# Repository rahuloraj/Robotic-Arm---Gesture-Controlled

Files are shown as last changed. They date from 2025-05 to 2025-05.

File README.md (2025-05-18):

<h1 align="center">Gesture Controlled Robotic Arm</h1>

<p align="center">
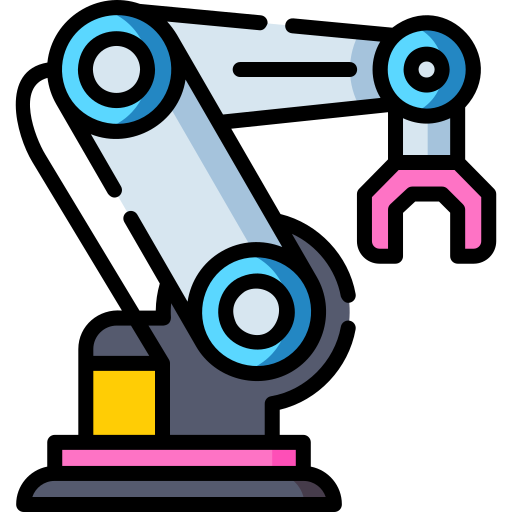
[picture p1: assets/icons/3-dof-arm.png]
3-DOF Arm
  
</p>

<details>
  <summary><h2>📚 Table of Contents (Click to Expand)</h2></summary>

- [📖 Project Description](#-project-description)
- [✨ Features](#-features)
- [⚙️ Installation Instructions](#️-installation-instructions)
- [🦾 Project Showcase](#-project-showcase)
- [🔧 Use Cases](#-use-cases)
- [🛣️ Future Plans](#️-future-plans)
- [🤝 Contributing](#-contributing)
- [📜 License](#-license)
- [🙏 Acknowledgments](#-acknowledgments)
  - [🤖 Meet the Team! 🤝](#-meet-the-team-)
- [📧 Contact Information](#-contact-information)
- [📝 Attribution](#-attribution)
</details>

---

## 📖 Project Description  

The **Gesture-Controlled Robotic Arm** is designed to automate repetitive tasks using hand gestures. The robotic arm consists of **four links**: a **base, two links, and an end effector**, enabling **pick-and-place functionality**.  

Control is achieved via a **glove-based gesture system**, equipped with **flex sensors and an accelerometer**, translating hand movements into precise robotic commands.

---

## ✨ Features  

🤖 4-Link Robotic Arm Structure
    ➤ Enables precise and flexible movement

🖐️ Gesture-Based Control
    ➤ Uses flex sensors and an accelerometer for intuitive interaction

📦 Pick-and-Place Functionality
    ➤ Automates repetitive tasks with ease

🧭 Intuitive User Interface
    ➤ Offers seamless and user-friendly control 

> **Note:**  
> The integration of a 4th link between the end effector and the robotic arm is part of our planned system expansion.  
> In the current release, the design has been optimized for stability, ease of control, and project timelines.  
> Full 4-link integration, offering enhanced dexterity and extended functionality, is scheduled for future updates.  
> Further design considerations and future rollout details are outlined in the [DESIGN.MD](./designs/DESIGN.MD) file.
---

## ⚙️ Installation Instructions  

- 🛠️ For installation instructions and to download the Arduino IDE, visit the [Arduino IDE Download Page](https://www.arduino.cc/en/software).
- Add the ESP32 Library to the ide [Instructions](https://docs.espressif.com/projects/arduino-esp32/en/latest/installing.html)
- To set up the project, follow these steps: 
- Clone the repository:
- ```bash
  git clone https://github.com/Robo-Linkers/Gesture-controlled-robotic-arm.git 
  ```
- Install any necessary dependencies [REQUIREMENTS](requirements.txt)
- Navigate to the project directory:
- ```cd Gesture-controlled-robotic-arm```
- In the `src` folder, you will find two Arduino code files: `Glove.ino` and `Power_Drive.ino`.
  - Upload `Glove.ino` to the ESP32 board that handles gesture recognition.
  - Upload `Power_Drive.ino` to the ESP32 board that controls the robotic arm's movements.
- Before uploading the codes to the boards, make sure to:
  - Edit the relevant fields in both files:
    - Set your WiFi SSID and Password in the code.  
    - Adjust any other parameters as necessary for your setup (e.g., GPIO pins, motor controls).

Once you've uploaded both codes to the respective boards, your setup should be ready for further testing.
- For building the hardware and assembling the robotic arm, refer to the detailed setup and wiring instructions in the [DESIGN.MD](./designs/DESIGN.MD) file. This includes schematics, PCB & hardware designs, and wiring connections necessary to physically construct the system.
-  All Markdown files are available as HTML in the [docs/](./docs) section — check it out for easy browsing and reference.
-  [README.HTML](https://html-preview.github.io/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), [DESIGN.HTML](https://html-preview.github.io/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), [TESTS.HTML](https://html-preview.github.io/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), [BOM.HTML](https://html-preview.github.io/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)
---

## 🚀 Usage Instructions  
- After setting up the hardware and software, wear the glove equipped with sensors, power on the robotic arm, and start performing gestures to control its movements.
  ### Components
  - Robotic Arm: 4-link structure with servos.
  - Glove Interface: Equipped with flex sensors and an accelerometer
  - Microcontroller: ESP32 or compatible board for processing input signals
  - Power Supply: AC power source for operation.
  ### Designs
  - For detailed information on the setup, schematics, and design documents related to the glove and robotic arm, refer to the Design Folder. It includes all the necessary diagrams and documentation to help you build the physical system and understand the circuitry.
  ### Testing
  - The tests folder contains Arduino sketches for testing individual components, including:
    - Flex sensors
    - Dual MPU6050
    - Power electronics (motors, servos)
  - If you encounter any errors, test each component individually to identify the source of the issue. 
  > It is **highly recommended** to test each component individually before full assembly to ensure everything is working correctly and to avoid complications during the final integration.

---

## 📂 Folder Structure  
```bash
Gesture-controlled-robotic-arm/
│   .gitignore
│   CONTRIBUTING.md
│   LICENSE
│   README.md
│   requirements.txt
│   TODO.MD
│   
├───assets
│   ├───icons
│   │       3-dof-arm.png
│   │       bill.png
│   │       binary-code.png
│   │       docs.png
│   │       pcb-board.png
│   │       schematic.png
│   │       testing.png
│   │
│   └───images
│           feature-excluded.png
│           mechanical-assembly-ss-front.png
│           mechanical-assembly-ss.png
│           Screenshot 2025-02-11 091135.png
│           Screenshot 2025-02-11 091319.png
│
├───designs
│   │   BASE v14.step
│   │   Bill_of_Materials_Electrical.pdf
│   │   BOM.MD
│   │   DESIGN.MD
│   │   Schematic_Glove-Gesture-Controlled-Robotic-Arm_2025-04-26.pdf
│   │   Schematic_Power-Drive-Gesture-Controlled-Robotic-Arm_2025-04-26.pdf
│   │
│   └───Solid-edge
│           BASE-v14-solid-edge.asm
│           BASE-v14-solid-edge.cfg
│
├───docs
├───logs
│       glove_control.log
│       power_drive.log
│
├───src
│       Glove.ino
│       Power_Drive.ino
│
├───tests
│   │   TESTS.MD
│   │
│   ├───Embedded Systems
│   │   ├───COMPLETE
│   │   │       COMPLETE.ino
│   │   │
│   │   ├───DUAL-MPU6050
│   │   │       DUAL-MPU6050.ino
│   │   │
│   │   └───FLEX-SENSORS
│   │           FLEX-SENSORS.ino
│   │
│   └───Power Electronics
│       ├───complete
│       │       complete.ino
│       │
│       ├───complete-dynamic
│       │       complete-dynamic.ino
│       │
│       ├───nema_17_test
│       │       nema_17_test.ino
│       │
│       └───servo_test
│               servo_test.ino
.
```
---

## 🦾 Project Showcase
<!-- Add vids, images etc -->

---

## 🔧 Use Cases  

💡 **Manufacturing** → Automating repetitive tasks like assembly & packaging  
🔧 **Remote Operation in Hazardous Environments** → Safely handling objects in high-risk areas such as labs or hot zones using remote gesture control
🎓 **Education** → Demonstrating robotics concepts in academic settings  
🧪 **Research** → Exploring human-robot interaction and automation  

---

## 🛣️ Future Plans
- 🚀 **Integrate the 4th Link**
  - Expand the robotic arm with a fourth link between the end effector and arm base to improve dexterity and range of motion.

- 🚀 **Enhance Gesture Recognition**
  - Implement advanced gesture processing algorithms for more fluid and natural control.

- 🚀 **Wireless Communication Optimization**
  - Improve reliability and response time of the ESP32-based communication system.

- 🚀 **Battery Power Support**
  - Add portable power options to make the system independent of a fixed AC supply and make a rechargeable solution for glove.

- 🚀 **Vision-Based Object Tracking**
  - Future iterations may incorporate a lightweight camera module for autonomous object detection and tracking.

- 🚀 **Mechanical Redesign**
  - Refine the mechanical structure for lighter weight and increased durability, including 3D printed or CNC-milled parts.

---

## 🤝 Contributing  
- Contributions are welcome! Please feel free to submit a pull request or open an issue if you have suggestions or improvements, for more details refer [CONTRIBUTING](CONTRIBUTING.md).

---

## 📜 License  

This project is licensed under the **MIT License**. Refer to the [LICENSE](LICENSE) file for more details.  

---

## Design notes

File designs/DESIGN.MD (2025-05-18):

<h1 align="center">Design Folder</h1>

<p align="center">
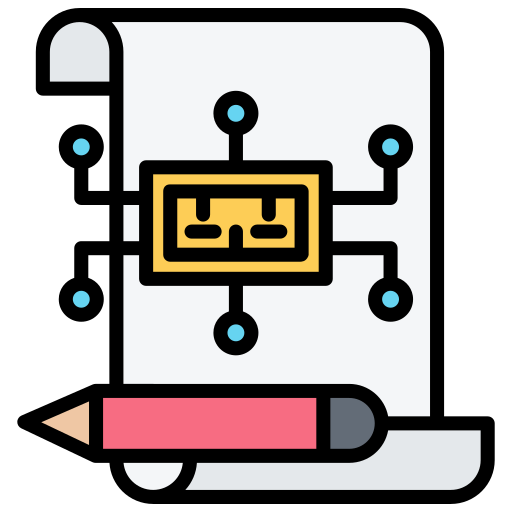
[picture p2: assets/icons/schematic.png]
Design
  
</p>

## Table of Contents
- [Table of Contents](#table-of-contents)
- [📖 Overview](#-overview)
- [🛠️ Implementation Note](#️-implementation-note)
- [📂 Schematic Files](#-schematic-files)
  - [🔌 1. Power Electronics Schematic](#-1-power-electronics-schematic)
  - [Final PCB for Power Drive](#final-pcb-for-power-drive)
  - [🖐️ 2. Embedded System Schematic](#️-2-embedded-system-schematic)
  - [Final PCB for Glove Control](#final-pcb-for-glove-control)
- [🛠️ Wiring Instructions](#️-wiring-instructions)
- [🦿 Mechanical Design Overview](#-mechanical-design-overview)
  - [📂 Mechanical Design Files](#-mechanical-design-files)
  - [🖼️ Final Mechanical Build](#️-final-mechanical-build)
  - [🛠️ Assembly Instructions](#️-assembly-instructions)
  - [⚠️ Mechanical Handling Notes](#️-mechanical-handling-notes)
    - [Image of the Feature Excluded:](#image-of-the-feature-excluded)
- [🔗 Useful Links](#-useful-links)

## 📖 Overview  

This folder contains three important schematic files related to the design of the Robotic Arm project. Each schematic serves a specific purpose and is crucial for the development and integration of the power electronics and embedded systems.
> 📄 All schematics are provided in PDF format for easy viewing and printing.
> All the voltages mentioned are in DC unless specified.
> Designed and documented by **IoRT Club** - Embedded & Power Crew.

---

## 🛠️ Implementation Note

You can implement the electronics in two ways:

- **Custom PCB**:  
  Build a dedicated PCB by referring to the provided schematics for a more compact and reliable design.

  You can design the PCB using free tools such as:
  - [KiCad](https://www.kicad.org/) — Open-source, highly customizable PCB design software.
  - [EasyEDA](https://easyeda.com/) — Browser-based and beginner-friendly PCB design platform.

  > **Note**: Both tools are free to use (with some limitations).    
  After completing your design, export the files in **Gerber format** and submit them to a PCB fabrication vendor for manufacturing.

- **Perfboard / Breadboard**:  
  Alternatively, for prototyping or quick builds, you can assemble the circuits manually on a perfboard by carefully following the schematic connections. 
  Using a perfboard is recommended if manufacturing a custom PCB is not feasible or practical.

> **Note**: Ensure proper wire management and soldering practices if you choose the perfboard method to maintain signal integrity and minimize errors.

---

## 📂 Schematic Files

### 🔌 1. Power Electronics Schematic 

- **File Name**: [Schematic_Power-Drive-Gesture-Controlled-Robotic-Arm_2025-04-26](Schematic_Power-Drive-Gesture-Controlled-Robotic-Arm_2025-04-26.pdf)
- **Description**: This schematic implements the power drive for the robotic arm, including the configuration for servos and motors. It outlines how power is managed and distributed to ensure optimal performance of the robotic arm's movements.
  - Handles the actuation part of the robotic arm including control for servos and a NEMA17 stepper motor.
  - Features motor driving using DRV8825 for stepper control and PCA9685 for multi-servo PWM output.
  - Power management done using LM2596 buck converter and dual LM7805 regulators.
- **Key ICs**:
  - ESP32-WROOM32
  - DRV8825 Stepper Motor Driver
  - PCA9685 16-Channel PWM Driver
  - LM2596 Adjustable Buck Converter
  - LM7805 Voltage Regulators
- **Notes**:
  - Main voltage input via XT60 connector (e.g., 12V supply).
  - Separate regulation for logic and motor sections to avoid noise.

> ⚠️ **Power Safety Warning**  
> 
> The Power Drive system is designed to operate using a **12V DC SMPS (Switched-Mode Power Supply)** rated at a minimum of **2.5A**.  
> 
> Please exercise extreme caution while handling the power system:
> - Ensure the SMPS is properly rated and from a reputable manufacturer.
> - Always verify polarity before connecting the supply to the circuit.
> - Never work on the circuit while the SMPS is powered ON.
> - Use appropriate fuses or protection circuits if possible.
> 
> 🔥 Mishandling the power supply can cause **serious damage to components** or **pose a fire hazard**.  
> Double-check all connections before powering the system.

### Final PCB for Power Drive
<div align="center">
<!-- PCB for Power Drive -->
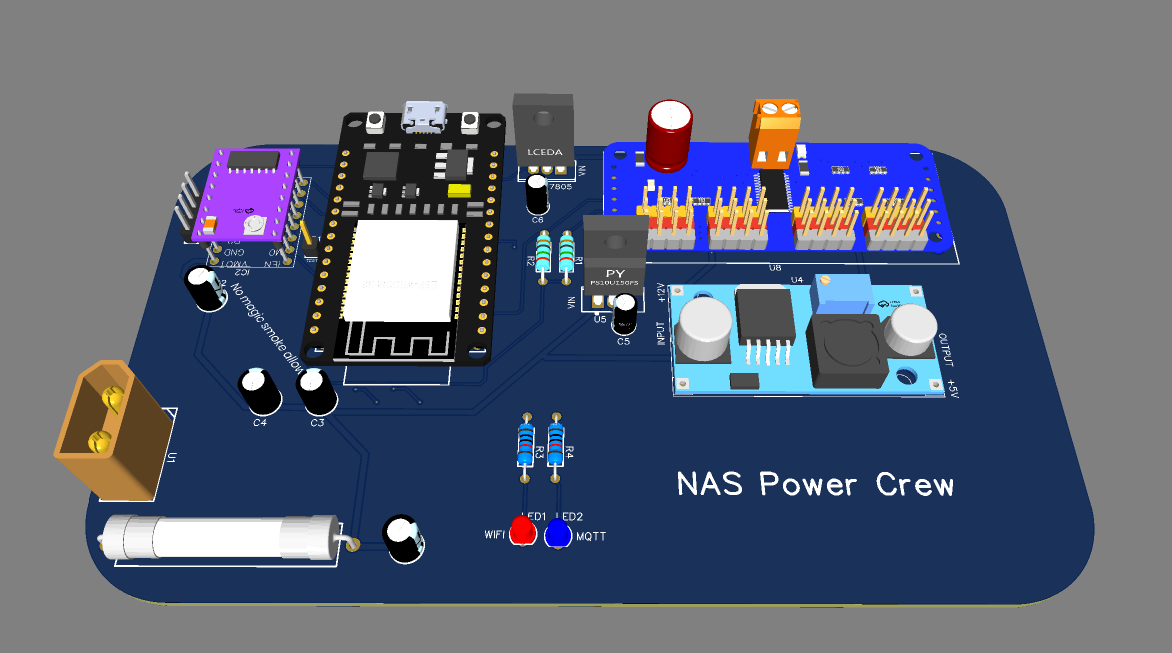
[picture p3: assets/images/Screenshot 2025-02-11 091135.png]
Final PCB for Power Drive

</div>

### 🖐️ 2. Embedded System Schematic 

- **File Name**: [Schematic_Glove-Gesture-Controlled-Robotic-Arm_2025-04-26](Schematic_Glove-Gesture-Controlled-Robotic-Arm_2025-04-26.pdf)
- **Description**: This schematic details the data acquisition part of the robotic arm, which captures user gestures through a glove interface. It is designed to facilitate communication between the user's gestures and the robotic arm's movements.
  - Captures the user gestures via an ESP32-WROOM32 module, two MPU6050 IMUs, and flex sensors.
  - Features voltage regulation using AMS1117 (3.3V) and LM7805 (5V) to power sensors reliably.
  - Includes TTP223 touch sensors for auxiliary control inputs.
- **Key ICs**:
  - ESP32-WROOM32
  - AMS1117-3.3 Voltage Regulator
  - LM7805 Voltage Regulator
  - Two MPU6050 Modules
  - Flex Sensors
- **Notes**:
  - Operates at 3.3V logic levels.
  - Input supply is 9V regulated down. Ensure the input provided is between 6V to 12V
  - >⚠️ **Note**: The touch sensor feature has been omitted from the current version and is planned for a future release

### Final PCB for Glove Control
<div align ="center">
<!-- Final GLove Control PCB -->
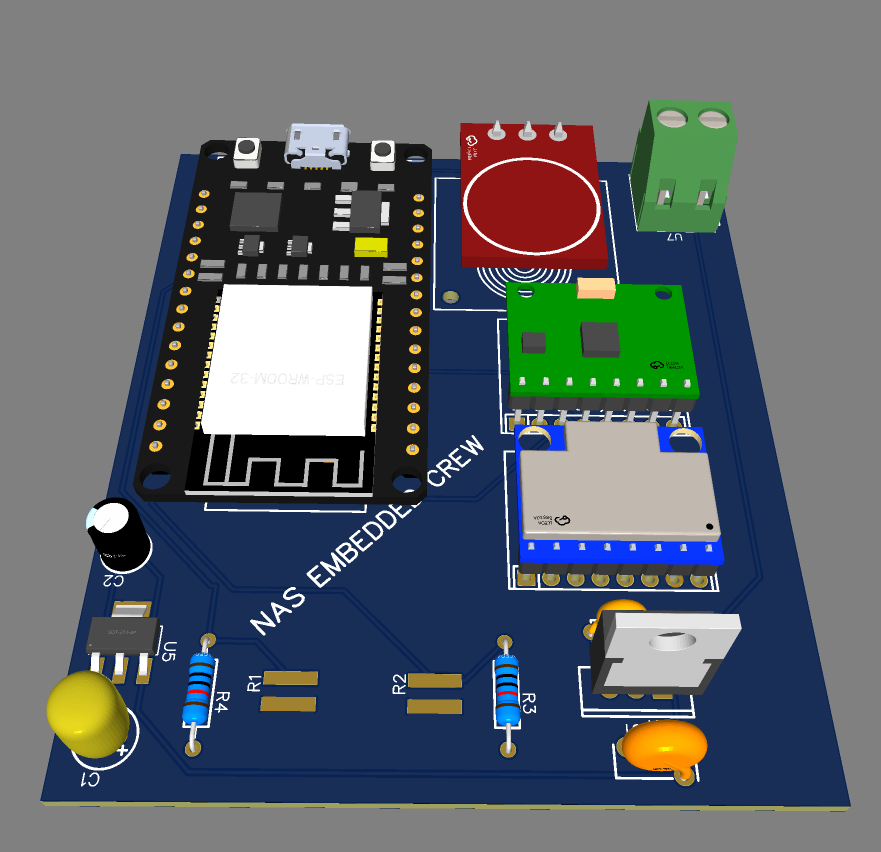
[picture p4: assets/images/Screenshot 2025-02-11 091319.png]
Final Glove Control PCB

</div>

---

## 🛠️ Wiring Instructions
- Ensure the all components are upto the rating as mentioned in the [BOM](Bill_of_Materials_Electrical.pdf)
- Make sure the pinout of your component matches the one provided in the schematic
- If a perfboard based design if being followed ensure that each voltage levels have different rails (think of it as a path for the current), the ground can occupy a single common rail.
-  [🔌 1. Power Electronics Schematic ](#-1-power-electronics-schematic) — 
   -  ESP32-WROOM32:
         - GPIO Pins to control servos via PCA9685.
         - SDA (GPIO21) → SDA of PCA9685
         - SCL (GPIO22) → SCL of PCA9685 

   - PCA 9685
      - Set the buck converter(LM2596) to output a steady voltage of 5.5V
      - The servos are connected to channel 0,1 and 2

   - DRV8825 (Stepper Motor Driver):  
       - DIR (Direction) and STEP pins connected to GPIOs of ESP32 for motor control.
       - Enable pin if required can be connected to a GPIO pin

- [🖐️ 2. Embedded System Schematic ](#️-2-embedded-system-schematic) —
  - MPU6050 IMUs:
    - SDA (GPIO21) and SCL (GPIO22) for I2C communication.
    - One of the MPU6050 IMU has its ADD pin (pin no 7) pulled high to _+3.3V_ this so that both the MPU sensors have unique I2C addresses.

  - Flex Sensors and TTP223 Touch Sensors:
    - Flex sensors and touch sensors connected to the ESP32 analog or digital inputs based on your design.

--- 

## 🦿 Mechanical Design Overview

This section covers the mechanical design aspects of the **Gesture-Controlled Robotic Arm**.  
The structure is designed to be lightweight, modular, and easily reproducible using commonly available materials.

---

### 📂 Mechanical Design Files

- **Formats**: `.step`, `.asm`

---

### 🖼️ Final Mechanical Build

<div align="center">
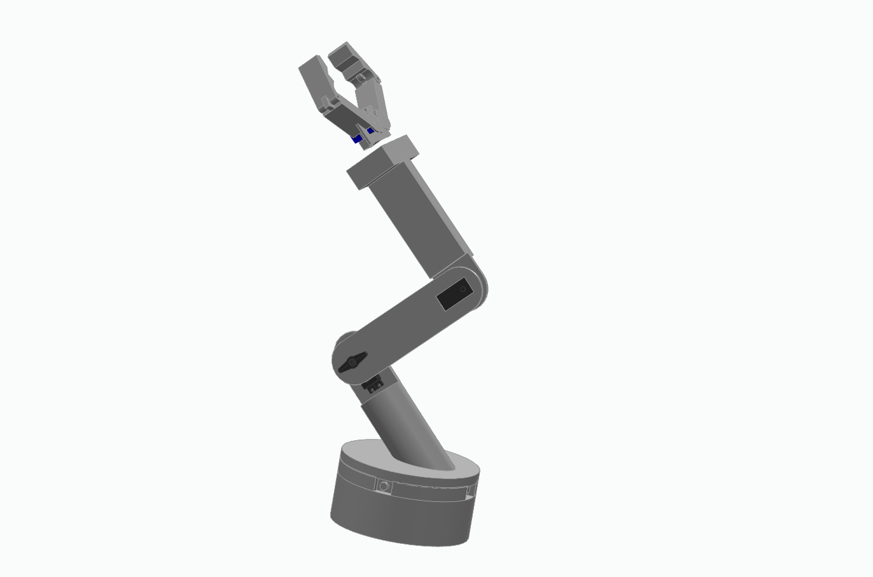
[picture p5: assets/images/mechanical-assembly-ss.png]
Robotic Arm Assembly Side View

</div>

<div align="center">
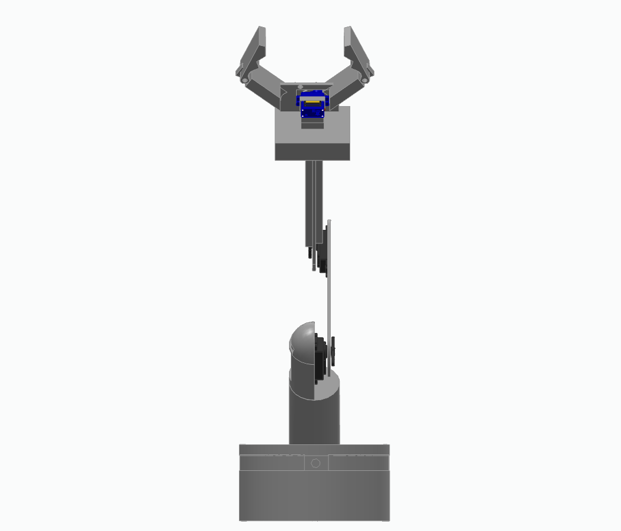
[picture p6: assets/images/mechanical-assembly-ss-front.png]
Robotic Arm Assembly Front View

</div>

---

### 🛠️ Assembly Instructions

- Begin assembly from the **base** to the **end effector**.
- Secure each joint firmly using M3 bolts and lock nuts.
- Align servos at their neutral (90°) or zero position (0°) position before fixing.
- Use threadlock on critical load-bearing screws.
- Maintain consistent spacing and ensure no binding during motion.
- For the base, use weight balancing if necessary (placing a metal plate or any apporpriate weights).

---

### ⚠️ Mechanical Handling Notes

> ⚠️ **Important:**  
>  
> - Avoid over-tightening bolts to prevent cracking plastic or aluminum parts.
> - Always test free movement manually before powering the arm.
> - Use washers where necessary to distribute load stress.
> - Use lubricant for ball bearings if necessary.
- Feature Exclusion: The integration of a 4th link between the end effector and the robotic arm, which would provide enhanced dexterity and range of motion, has not been implemented in this version of the design. This feature is part of our future plans and will be incorporated in a subsequent update to further improve the system's functionality.

#### Image of the Feature Excluded:
- The servo will be placed in the final design but wont be utilised for movement. _The feature has been circled in green_
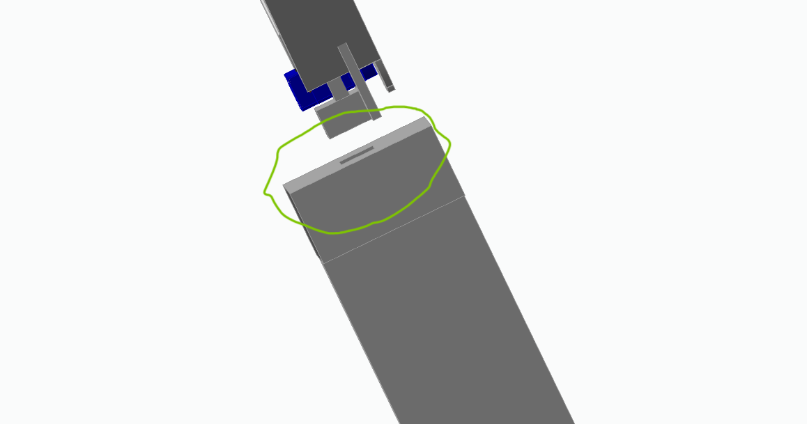
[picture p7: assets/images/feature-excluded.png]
Image of Feature Excluded


> ⚠️ **Warning** **3D Printing Tolerance Issues:** Significant tolerance issues were encountered during the 3D printing and mechanical assembly of the robotic arm. Misalignments, incorrect fits, and dimensional inaccuracies affected the integration of multiple components. It is **strongly recommended** to carefully inspect, measure, and, if necessary, modify the 3D models before printing. Pay special attention to part interfaces, mounting holes, and moving joints to ensure a smooth assembly and functional operation.

---

## 🔗 Useful Links
- [PCA9685 Datasheet and Pinout](https://www.espboards.dev/sensors/pca9685/#specs)
- [DRV8825 Datasheet and Pinout](https://www.makerguides.com/drv8825-stepper-motor-driver-arduino-tutorial/)
- [ESP32 Datasheet and Pinout](https://randomnerdtutorials.com/getting-started-with-esp32/)
- [MPU6050 Datasheet and Pinout](https://lastminuteengineers.com/mpu6050-accel-gyro-arduino-tutorial/)
- [KiCAD Basics](https://www.youtube.com/playlist?list=PLn6004q9oeqGl91KifK6xHGuqvXGb374G)
- [Soldering Tutorial — 1](https://www.instructables.com/A-Comprehensive-Guide-to-Soldering-Techniques-Tool/)
- [Soldering Tutorial — 2](https://www.sciencebuddies.org/science-fair-projects/references/how-to-solder)
- [MG995 3D MODEL](https://grabcad.com/library/mg995-servo-3)
- [SG90 3D MODEL](https://grabcad.com/library/sg90-micro-servo-9g-tower-pro-1)
- [Robotic Arm Collection](https://grabcad.com/library?page=1&time=all_time&query=robotic%20arm)
  - Please note that the design available for the robotic arm are provided for reference purposes only. While they offer valuable and powerful insights, our design may differ in complexity and features, as we have opted for a simpler, more modular approach.
  
---

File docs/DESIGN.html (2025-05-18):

# Design Folder

Design

## 📖 Overview

This folder contains three important schematic files related to the design of the Robotic Arm project. Each schematic serves a specific purpose and is crucial for the development and integration of the power electronics and embedded systems. > 📄 All schematics are provided in PDF format for easy viewing and printing. > All the voltages mentioned are in DC unless specified. > Designed and documented by IoRT Club - Embedded & Power Crew.

## 🛠️ Implementation Note

You can implement the electronics in two ways:

- Custom PCB: Build a dedicated PCB by referring to the provided schematics for a more compact and reliable design.
  You can design the PCB using free tools such as:
  - KiCad (https://www.kicad.org/) — Open-source, highly customizable PCB design software.
  - EasyEDA (https://easyeda.com/) — Browser-based and beginner-friendly PCB design platform.

Note: Both tools are free to use (with some limitations).
After completing your design, export the files in Gerber format and submit them to a PCB fabrication vendor for manufacturing.

- Perfboard / Breadboard: Alternatively, for prototyping or quick builds, you can assemble the circuits manually on a perfboard by carefully following the schematic connections. Using a perfboard is recommended if manufacturing a custom PCB is not feasible or practical.

Note: Ensure proper wire management and soldering practices if you choose the perfboard method to maintain signal integrity and minimize errors.

## 📂 Schematic Files

### 🔌 1. Power Electronics Schematic

- File Name: Schematic_Power-Drive-Gesture-Controlled-Robotic-Arm_2025-04-26
- Description: This schematic implements the power drive for the robotic arm, including the configuration for servos and motors. It outlines how power is managed and distributed to ensure optimal performance of the robotic arm’s movements.
  - Handles the actuation part of the robotic arm including control for servos and a NEMA17 stepper motor.
  - Features motor driving using DRV8825 for stepper control and PCA9685 for multi-servo PWM output.
  - Power management done using LM2596 buck converter and dual LM7805 regulators.
- Key ICs:
  - ESP32-WROOM32
  - DRV8825 Stepper Motor Driver
  - PCA9685 16-Channel PWM Driver
  - LM2596 Adjustable Buck Converter
  - LM7805 Voltage Regulators
- Notes:
  - Main voltage input via XT60 connector (e.g., 12V supply).
  - Separate regulation for logic and motor sections to avoid noise.

⚠️ Power Safety Warning

The Power Drive system is designed to operate using a 12V DC SMPS (Switched-Mode Power Supply) rated at a minimum of 2.5A.

Please exercise extreme caution while handling the power system: - Ensure the SMPS is properly rated and from a reputable manufacturer. - Always verify polarity before connecting the supply to the circuit. - Never work on the circuit while the SMPS is powered ON. - Use appropriate fuses or protection circuits if possible.

🔥 Mishandling the power supply can cause serious damage to components or pose a fire hazard.
Double-check all connections before powering the system.

### Final PCB for Power Drive

Final PCB for Power Drive

### 🖐️ 2. Embedded System Schematic

- File Name: Schematic_Glove-Gesture-Controlled-Robotic-Arm_2025-04-26
- Description: This schematic details the data acquisition part of the robotic arm, which captures user gestures through a glove interface. It is designed to facilitate communication between the user’s gestures and the robotic arm’s movements.
  - Captures the user gestures via an ESP32-WROOM32 module, two MPU6050 IMUs, and flex sensors.
  - Features voltage regulation using AMS1117 (3.3V) and LM7805 (5V) to power sensors reliably.
  - Includes TTP223 touch sensors for auxiliary control inputs.
- Key ICs:
  - ESP32-WROOM32
  - AMS1117-3.3 Voltage Regulator
  - LM7805 Voltage Regulator
  - Two MPU6050 Modules
  - Flex Sensors
- Notes:
  - Operates at 3.3V logic levels.
  - Input supply is 9V regulated down. Ensure the input provided is between 6V to 12V

### Final PCB for Glove Control

Final Glove Control PCB

## 🛠️ Wiring Instructions

- Ensure the all components are upto the rating as mentioned in the BOM
- Make sure the pinout of your component matches the one provided in the schematic
- If a perfboard based design if being followed ensure that each voltage levels have different rails (think of it as a path for the current), the ground can occupy a single common rail.
- 🔌 1. Power Electronics Schematic —
  - ESP32-WROOM32:
    - GPIO Pins to control servos via PCA9685.
    - SDA (GPIO21) → SDA of PCA9685
    - SCL (GPIO22) → SCL of PCA9685
  - PCA 9685
    - Set the buck converter(LM2596) to output a steady voltage of 5.5V
    - The servos are connected to channel 0,1 and 2
  - DRV8825 (Stepper Motor Driver):
    - DIR (Direction) and STEP pins connected to GPIOs of ESP32 for motor control.
    - Enable pin if required can be connected to a GPIO pin
- 🖐️ 2. Embedded System Schematic —
  - MPU6050 IMUs:
    - SDA (GPIO21) and SCL (GPIO22) for I2C communication.
    - One of the MPU6050 IMU has its ADD pin (pin no 7) pulled high to +3.3V this so that both the MPU sensors have unique I2C addresses.
  - Flex Sensors and TTP223 Touch Sensors:
    - Flex sensors and touch sensors connected to the ESP32 analog or digital inputs based on your design.

## 🦿 Mechanical Design Overview

This section covers the mechanical design aspects of the Gesture-Controlled Robotic Arm.
The structure is designed to be lightweight, modular, and easily reproducible using commonly available materials.

### 📂 Mechanical Design Files

- Formats: .step, .asm

### 🖼️ Final Mechanical Build

Robotic Arm Assembly Side View

Robotic Arm Assembly Front View

### 🛠️ Assembly Instructions

- Begin assembly from the base to the end effector.
- Secure each joint firmly using M3 bolts and lock nuts.
- Align servos at their neutral (90°) position before fixing.
- Use threadlock on critical load-bearing screws.
- Maintain consistent spacing and ensure no binding during motion.
- For the base, use weight balancing if necessary (suggest placing a metal plate).

### ⚠️ Mechanical Handling Notes

⚠️ Important:

- Avoid over-tightening bolts to prevent cracking plastic or aluminum parts.
- Always test free movement manually before powering the arm.
- Use washers where necessary to distribute load stress.
- Use lubricant for ball bearings if necessary.
- Feature Exclusion: The integration of a 4th link between the end effector and the robotic arm, which would provide enhanced dexterity and range of motion, has not been implemented in this version of the design. This feature is part of our future plans and will be incorporated in a subsequent update to further improve the system’s functionality.

#### Image of the Feature Excluded:

- The servo will be placed in the final design but wont be utilised for movement. The feature has been circled in green

Image of Feature Excluded

⚠️ Warning 3D Printing Tolerance Issues: During the 3D printing process, some tolerance faults were observed in the final model, which could impact the fit and function of certain parts. It is essential to double-check the dimensions of each part before proceeding with 3D printing to ensure that everything fits together as intended.

## 🔗 Useful Links

- PCA9685 Datasheet and Pinout (https://www.espboards.dev/sensors/pca9685/#specs)
- DRV8825 Datasheet and Pinout (https://www.makerguides.com/drv8825-stepper-motor-driver-arduino-tutorial/)
- ESP32 Datasheet and Pinout (https://randomnerdtutorials.com/getting-started-with-esp32/)
- MPU6050 Datasheet and Pinout (https://lastminuteengineers.com/mpu6050-accel-gyro-arduino-tutorial/)
- KiCAD Basics (https://www.youtube.com/playlist?list=PLn6004q9oeqGl91KifK6xHGuqvXGb374G)
- Soldering Tutorial — 1 (https://www.instructables.com/A-Comprehensive-Guide-to-Soldering-Techniques-Tool/)
- Soldering Tutorial — 2 (https://www.sciencebuddies.org/science-fair-projects/references/how-to-solder)
- MG995 3D MODEL (https://grabcad.com/library/mg995-servo-3)
- SG90 3D MODEL (https://grabcad.com/library/sg90-micro-servo-9g-tower-pro-1)
- Robotic Arm Collection (https://grabcad.com/library?page=1&time=all_time&query=robotic%20arm)
  - Please note that the design available for the robotic arm are provided for reference purposes only. While they offer valuable insights, our design may differ in complexity and features, as we have opted for a simpler, more modular approach.

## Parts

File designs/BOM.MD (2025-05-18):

<h1 align="center">Bill of Materials</h1>

<p align="center">
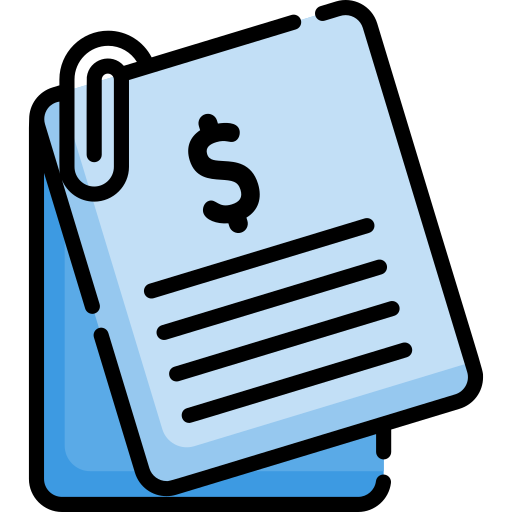
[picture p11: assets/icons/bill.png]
Bill
  
</p>

This document lists the components used in the Gesture-Controlled Robotic Arm project.

## 📂 Electrical BOM
A detailed list of all electronic components, including ICs, resistors, capacitors, connectors, and other necessary parts for the electrical design.

[Electrical](./Bill_of_Materials_Electrical.pdf)

## 📂 Mechanical BOM
A comprehensive list of all mechanical parts, including motors, servos, structural components, and fasteners for the arm assembly.

[Mechanical](./B)

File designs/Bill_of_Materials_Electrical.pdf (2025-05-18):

### Bill of Materials

S.NO | Part Name | Assemblies & Subassemblies | Part Description | Unit Cost | Quantity | Total Cost | Procurement Details
1 | LM7805CT | Power Drive | 5V regulator | ₹ 15.00 | 4 | ₹ 60.00 | 3 required in design
2 | AMS1117-3.3 | Gesture Control | 3.3V regulator | ₹ 25.00 | 2 | ₹ 50.00 | 1 required in design
3 | ESP-32-WROOM | Power Drive and Gesture Control | MCU | ₹ 500.00 | 2 | ₹ 1,000.00
4 | MPU-6050 | Gesture Control | Gyroscope and accel | ₹ 200.00 | 3 | ₹ 600.00 | 2 required in design
5 | TTP223 | Gesture Control | Touch Sensor | ₹ 20.00 | 2 | ₹ 40.00 | 1 required in design
6 | DRV8825 | Power Drive | Stepper Motor Driver | ₹ 300.00 | 1 | ₹ 300.00
7 | FLEX SENSOR 4.5" LENGTH | Gesture Control | Flex Sensors | ₹ 450.00 | 4 | ₹ 1,800.00 | 2 required in design
8 | 10k ohm resistor | Gesture Control | resistor 1/4W | ₹ 1.00 | 10 | ₹ 10.00 | 2 required in design
9 | 100uf | Power Drive | capacitors | ₹ 2.00 | 4 | ₹ 8.00 | 2 required in design
10 | 220nf | Power Drive | capacitors | ₹ 2.00 | 4 | ₹ 8.00 | 2 required in design
11 | 100nf | Power Drive and Gesture Control | capacitors | ₹ 1.00 | 4 | ₹ 4.00 | 3 required in design
12 | 22uf | Gesture Control | capacitors | ₹ 2.00 | 4 | ₹ 8.00 | 1 required in design
13 | 10uf | Gesture Control | capacitors | ₹ 2.00 | 5 | ₹ 10.00 | 1 required in design
14 | 2.4k res | Power Drive | resistor 1/4W | ₹ 1.00 | 4 | ₹ 4.00 | 2 required in design
15 | LM2596S-5.0/NOPB | Power Drive | Buck Converter | ₹ 75.00 | 1 | ₹ 75.00
16 | PCA9685 | Power Drive | Servo Driver | ₹ 450.00 | 1 | ₹ 450.00
17 | NEMA 17 | Power Drive | Stepper Motor | ₹ 600.00 | 1 | ₹ 600.00
18 | 12V PSU | Power Drive | Power Supply | ₹ 868.00 | 1 | ₹ 868.00
19 | 3 Pin Cord | Power Drive | Power Supply wire | ₹ 90.00 | 1 | ₹ 90.00
20 | Connectors | Power Drive and Gesture Control | Connectors for PCB | ₹ 50.00 | 1 | ₹ 50.00
21 | Pin Headers | Power Drive and Gesture Control | Pin Headers for PCB | ₹ 20.00 | 2 | ₹ 40.00
22 | Fuse and Fuse holder | Power Drive | Fuse (minimum 2.5A) | ₹ 27.00 | 1 | ₹ 27.00
23 | MG995 | Power Drive | Servo | ₹ 310.00 | 2 | ₹ 620.00
24 | SG 90 | Power Drive | Servo | ₹ 90.00 | 2 | ₹ 180.00
Total = | ₹ | 6,902.00
Project Name | Gesture Controlled Robotic Arm
Assembly Name | Power Drive and Gesture Control
Assembly Revision | 1.1
Date of Approval
Total Piece | 66
Total Cost | ₹ 6,902.00

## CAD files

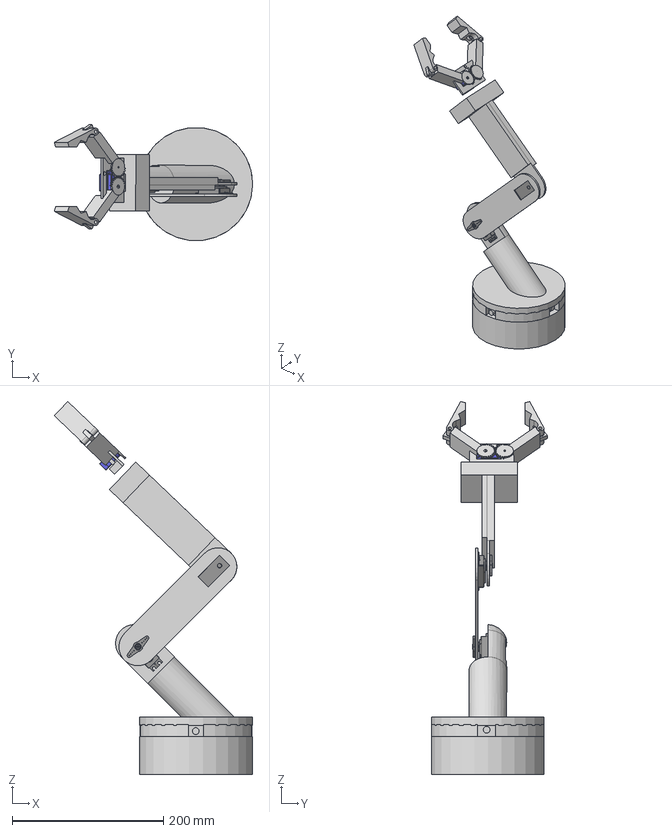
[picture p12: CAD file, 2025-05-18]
designs/BASE v14.step
262.5 x 153.1 x 493.4 mm
BASE_1
RBASE
M5 SCREWS
M5 BEARING
M5 BEARING 2
M5 SCREWS 3
M5 SCREWS 4
M5 BEARING 3
M5 BEARING 4
TOWER PRO MG-995, ANALOG SERVO, BODY, TOP (1) x 2
Link1
Link2
Link3
EEB
M5 SCREWS 2
SG90 - Micro Servo 9g - Tower Pro
Spur Gear (25 teeth)
EE arm
EE arm(Mirror)
Component27(Mirror)
Component28(Mirror)

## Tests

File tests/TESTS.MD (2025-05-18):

<h1 align="center">🧪 Tests Folder</h1>

<p align="center">
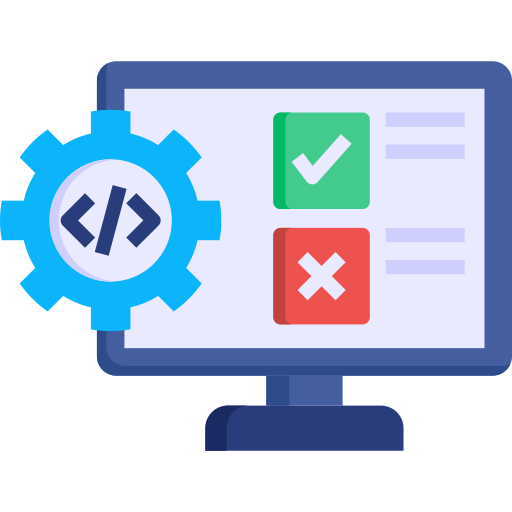
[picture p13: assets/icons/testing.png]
Tests
  
</p>

This directory contains tests to ensure code reliability and functionality for Embedded Systems and Power Electronics projects.

## ✅ Purpose

- Validate code correctness for various hardware and software components.
- Detect bugs and errors in embedded system and power electronics designs.
- Maintain code quality and ensure proper operation of electronic systems.
---

## 📂 Folder Structure

The `tests` folder is organized into two main categories:

-   **Embedded Systems**: Contains tests related to embedded systems projects.

    -   `COMPLETE`: Contains a completed embedded systems project.
    -   `DUAL-MPU6050`: Contains tests for a dual MPU6050 sensor setup.
    -   `FLEX-SENSORS`: Contains tests for flex sensors.

-   **Power Electronics**: Contains tests related to power electronics projects.

    -   `complete`: Contains a complete power electronics project, the stepper and servo **don't** move together.
    -   `complete-dynamic`: Contains tests for a complete dynamic power electronics system, by dynamic what is meant is both the servo and stepper motors move together. This test code will aid in determining the maximum current draw needed.
    -   `nema_17_test`: Contains tests for NEMA 17 stepper motors.
    -   `servo_test`: Contains tests for servo motors.
---

## ⚙️ Usage

Each subfolder contains an `.ino` file, which can be opened and run using the Arduino IDE. Follow these steps to run the tests:

1.  Open the desired `.ino` file in the Arduino IDE.
2.  Connect the appropriate hardware components to your Arduino board.
3.  Upload the code to the Arduino board.
4.  Monitor the output and verify the results.

---

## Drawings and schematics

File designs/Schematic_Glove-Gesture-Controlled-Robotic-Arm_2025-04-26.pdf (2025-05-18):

## GND

## PoWer In

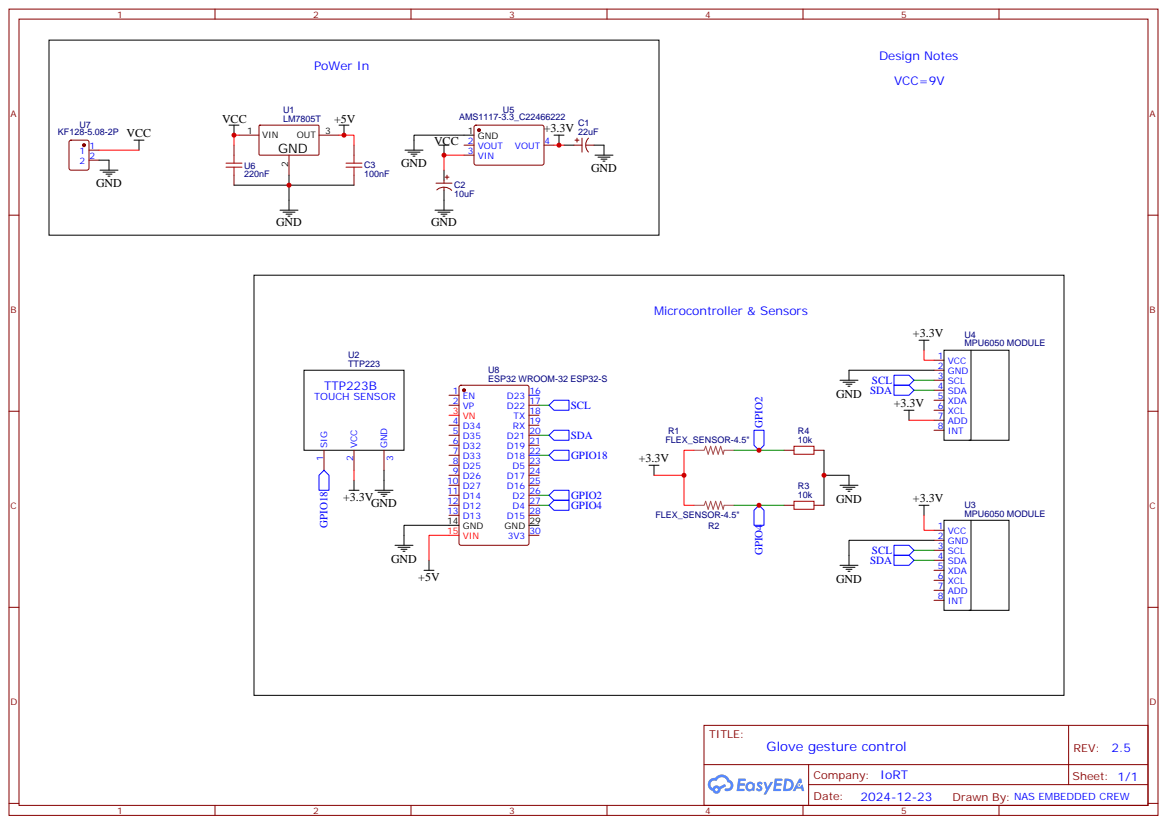
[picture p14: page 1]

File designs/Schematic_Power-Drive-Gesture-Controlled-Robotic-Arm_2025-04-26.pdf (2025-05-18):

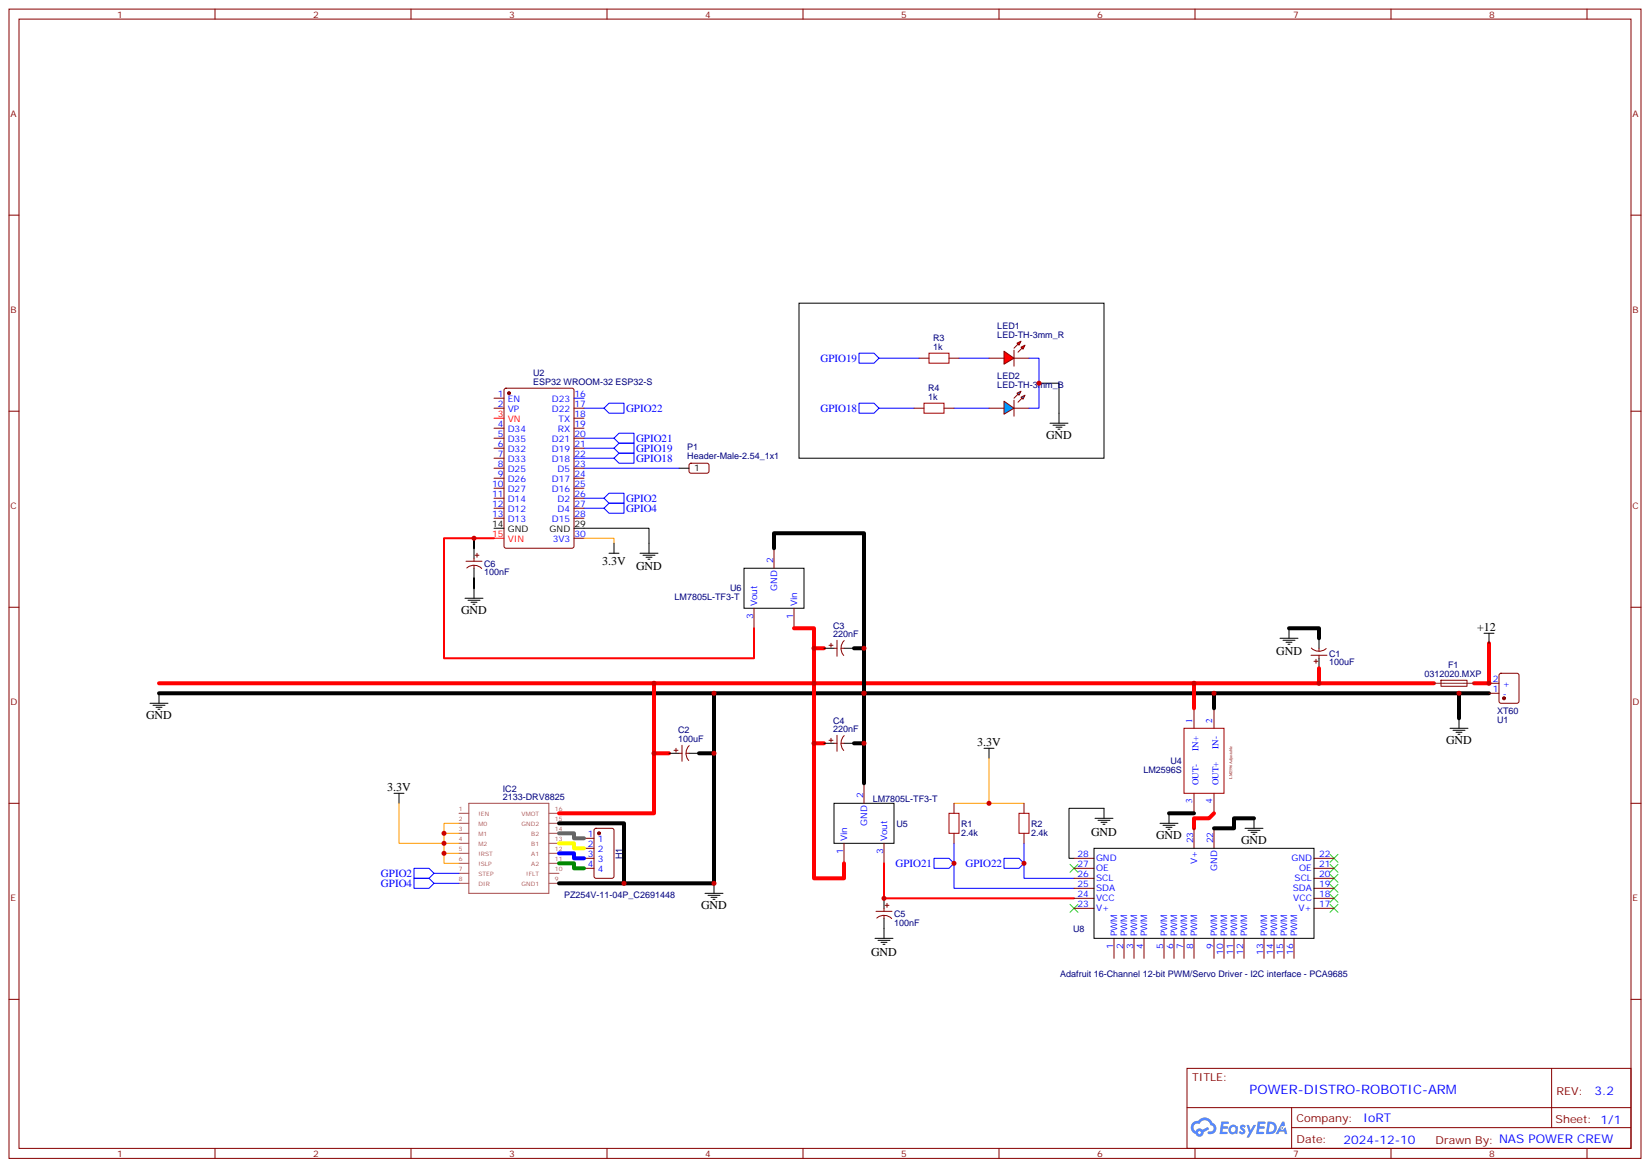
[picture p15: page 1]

Adafruit 16-Channel 12-bit PWM/Servo Driver - I2C interface - PCA9685

Drawn By: NAS POWER CREW

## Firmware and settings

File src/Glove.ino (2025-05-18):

#include <WiFi.h>
#include <PubSubClient.h>
#include <Wire.h>
#include <MPU6050.h>

// Wi-Fi and MQTT Credentials
const char *ssid = "Your_SSID";
const char *password = "Your_PASSWORD";
const char *mqttServer = "broker.emqx.io";
const int mqttPort = 1883;
const char *mqttUser = "Your_MQTT_Username";
const char *mqttPassword = "Your_MQTT_Password";

// MQTT client
WiFiClient espClient;
PubSubClient mqttClient(espClient);

// MPU6050 Sensors (with different I2C addresses)
MPU6050 mpuServo(0x68);   // AD0 = GND default address
MPU6050 mpuStepper(0x69); // AD0 = VCC

// FSR Configuration
#define FSR1_PIN 34     // FSR for Gripper
#define FSR2_PIN 35     // Second FSR for additional grip check
#define Touch_Sensor 18 // Touch Sensor Pin
int fsr1Value, fsr2Value;

// Kalman Filter Variables
float angleServoX, angleServoY2, angleStepperY;
float biasServoX = 0, biasServoY2 = 0, biasStepperY = 0;
float P_ServoX[2][2] = {{1, 0}, {0, 1}};
float P_ServoY2[2][2] = {{1, 0}, {0, 1}};
float P_StepperY[2][2] = {{1, 0}, {0, 1}};
const float kalmanQ = 0.001, kalmanR = 0.03, dt = 0.05; // Smooth update delay
bool gripLatched = false;                               // Latched grip state
bool lastTouchState = LOW;                              // Previous sensor state
unsigned long lastDebounceTime = 0;
const unsigned long debounceDelay = 50; // Adjust as needed

// Function Prototypes
void connectToWiFi();
void ensureWiFiConnection();
void connectToMQTT();
void ensureMQTTConnection();
void kalmanFilter(float &angle, float &bias, float newAngle, float newRate);
void sendAnglesToMQTT(float angleServoX, float angleServoY2, float angleStepperY, bool gripActive);

// Delay for smoother updates
unsigned long previousMillis = 0;
const long interval = 200; // Adjusted update interval for smooth transition

/**
 * @brief Initializes the serial communication, I2C bus, and MPU6050 sensors.
 *        Connects to WiFi and MQTT broker.
 * @details
 * - Initializes serial communication with a baud rate of 115200.
 * - Initializes the I2C bus.
 * - Initializes two MPU6050 sensors and checks for a successful connection.
 *   If either sensor fails to connect, the function enters an infinite loop.
 * - Connects to WiFi with the provided ssid and password.
 * - Connects to the MQTT broker at the provided server and port.
 */
void setup()
{
    Serial.begin(115200);
    Wire.begin();

    // Initialize MPU6050 sensors
    mpuServo.initialize();
    mpuStepper.initialize();

    // Touch sensor as input
    // pinMode(Touch_Sensor, INPUT); // Uncomment if using touch sensor

    if (!mpuServo.testConnection() || !mpuStepper.testConnection())
    {
        Serial.println("MPU6050 initialization failed!");
        while (1)
            ;
    }

    mqttClient.setServer(mqttServer, mqttPort);
    connectToWiFi();
    connectToMQTT();
}

/**
 * @brief Main loop of the program.
 *        Ensures WiFi and MQTT connections are established and maintained.
 *        Reads data from the MPU6050 sensors and the FSR sensors.
 *        Applies Kalman filter to the data for smoother transitions.
 *        Sends the filtered data to the MQTT broker.
 * @details
 * - Ensures WiFi connection with the provided ssid and password.
 * - Ensures MQTT connection with the provided server and port.
 * - Reads data from the MPU6050 sensors for the servos and the stepper motor.
 * - Applies the Kalman filter to the data to reduce noise and jitter.
 * - Reads data from the FSR sensors and Touch sensor to detect grip activity.
 * - Sends the filtered data to the MQTT broker.
 */
void loop()
{
    ensureWiFiConnection();
    ensureMQTTConnection();

    unsigned long currentMillis = millis();
    if (currentMillis - previousMillis >= interval)
    {
        previousMillis = currentMillis;

        // Read MPU6050 data for Servo and Stepper
        int16_t ax, ay, az, gx, gy, gz;
        mpuServo.getMotion6(&ax, &ay, &az, &gx, &gy, &gz);
        float accelAngleX = atan2(ay, sqrt(ax * ax + az * az)) * 180.0 / M_PI;
        float accelStepperY = atan2(-ax, sqrt(ay * ay + az * az)) * 180.0 / M_PI;
        float gyroRateX = gx / 131.0, gyroStepperY = gy / 131.0;
        kalmanFilter(angleServoX, biasServoX, accelAngleX, gyroRateX, P_ServoX);          // 1st servo "X" angle
        kalmanFilter(angleStepperY, biasStepperY, accelStepperY, gyroStepperY, P_StepperY); // Stepper "Y" angle

        // Read MPU6050 data for 2nd Servo
        int16_t ax2, ay2, az2, gx2, gy2, gz2;
        mpuStepper.getMotion6(&ax2, &ay2, &az2, &gx2, &gy2, &gz2);
        float accelAngleY2 = atan2(-ax2, sqrt(ax2 * ax2 + az2 * az2)) * 180.0 / M_PI;
        float gyroRateY2 = gy2 / 131.0;
        kalmanFilter(angleServoY2, biasServoY2, accelAngleY2, gyroRateY2, P_ServoY2);

        // Read FSR sensor values
        fsr1Value = analogRead(FSR1_PIN);
        fsr2Value = analogRead(FSR2_PIN);

        // Read touch sensor value. Uncomment lines below if using touch sensor
        // bool reading = digitalRead(Touch_Sensor);

        // if (reading != lastTouchState) {
        //     lastDebounceTime = millis();  // reset debounce timer
        // }

        // if ((millis() - lastDebounceTime) > debounceDelay) {
        //     if (reading == HIGH && lastTouchState == LOW) {
        //         gripLatched = !gripLatched; // toggle grip state only on valid rising edge
        //     }
        // }

        // lastTouchState = reading;

        // Determine grip status
        bool gripActive = (fsr1Value > 200 || fsr2Value > 50 || gripLatched);

        // Send data via MQTT
        sendAnglesToMQTT(angleServoX, angleServoY2, angleStepperY, gripActive);
    }
}

/**
 * @brief Publishes the angles of the robotic arm's servos and
 *        the stepper motor, as well as the grip status, to the
 *        MQTT broker.
 * @param[in] angleServoX Angle of the servo motor controlling
 *                        the base rotation in degrees.
 * @param[in] angleServoY Angle of the servo motor controlling
 *                        the shoulder rotation in degrees.
 * @param[in] angleStepperX Angle of the stepper motor controlling
 *                          the elbow rotation in degrees.
 * @param[in] gripActive true if the grip is active, false otherwise.
 */
void sendAnglesToMQTT(float angleServoX, float angleServoY2, float angleStepperY, bool gripActive)
{
    char msg[50];
    snprintf(msg, sizeof(msg), "SX:%.2f,SY2:%.2f,ST:%.2f,GR:%d", angleServoX, angleServoY2, angleStepperY, gripActive);
    mqttClient.publish("robot/angles", msg);
    
    // Debugging Statements below uncomment to see the output
//     if (!mqttClient.publish("robot/angles", msg)) {
//       Serial.println("Failed to publish angles!");
//   } else {
//       Serial.print("Published angles: ");
//       Serial.println(msg);
//   }
}


/**
 * @brief Applies the Kalman filter to estimate the angle and bias.
 * @param[in,out] angle Reference to the angle estimate, updated with the filtered value.
 * @param[in,out] bias Reference to the bias estimate, updated with the filtered value.
 * @param[in] newAngle The new angle measurement.
 * @param[in] newRate The new rate measurement from the gyroscope.
 * @param[in,out] P The error covariance matrix, updated during the filtering process.
 * @details
 * - The function uses the Kalman filter algorithm to reduce noise in angle and bias readings.
 * - It updates the angle and bias using a prediction-correction model.
 * - The error covariance matrix P is adjusted to reflect the uncertainty in the estimates.
 */
void kalmanFilter(float &angle, float &bias, float newAngle, float newRate, float P[2][2])
{
    float rate = newRate - bias;
    angle += dt * rate;
    P[0][0] += dt * (dt * P[1][1] - P[0][1] - P[1][0] + kalmanQ);
    P[0][1] -= dt * P[1][1];
    P[1][0] -= dt * P[1][1];
    P[1][1] += kalmanQ * dt;
    float S = P[0][0] + kalmanR;
    float K[2] = {P[0][0] / S, P[1][0] / S};
    float y = newAngle - angle;
    angle += K[0] * y;
    bias += K[1] * y;
    P[0][0] -= K[0] * P[0][0];
    P[0][1] -= K[0] * P[0][1];
    P[1][0] -= K[1] * P[0][0];
    P[1][1] -= K[1] * P[0][1];
}

/**
 * @brief Ensures that the MQTT client is connected.
 * @details
 * - Checks if the MQTT client is currently connected to the broker.
 * - If not connected, attempts to establish a connection by calling connectToMQTT().
 */
void ensureMQTTConnection()
{
    if (!mqttClient.connected())
    {
        connectToMQTT();
    }
}

/**
 * @brief Establishes a connection to the MQTT broker.
 * @details
 * - Connects to the MQTT broker using the client ID, username, and password.
 * - If the connection fails, prints the error state and waits for 2 seconds before retrying.
 * - Repeats until the connection is established.
 */
void connectToMQTT()
{
    while (!mqttClient.connected())
    {
        Serial.print("Connecting to MQTT...");
        if (mqttClient.connect("ESP32_DATA_ACQ", mqttUser, mqttPassword))
        {
            Serial.println("Connected to MQTT Broker.");
        }
        else
        {
            Serial.print("Failed. State=");
            Serial.println(mqttClient.state());
            delay(2000);
        }
    }
}

/**
 * @brief Ensures that the Wi-Fi connection is established.
 * @details
 * - Checks if the Wi-Fi connection is currently established.
 * - If not connected, attempts to establish a connection by calling connectToWiFi().
 */
void ensureWiFiConnection()
{
    if (WiFi.status() != WL_CONNECTED)
    {
        connectToWiFi();
    }
}

/**
 * @brief Establishes a connection to the Wi-Fi network.
 * @details
 * - Initiates connection to the Wi-Fi using the provided SSID and password.
 * - Continuously checks the connection status until connected, displaying
 *   progress via serial output.
 * - Prints a confirmation message upon successful connection.
 */
void connectToWiFi()
{
    Serial.print("Connecting to Wi-Fi: ");
    Serial.println(ssid);
    WiFi.begin(ssid, password);
    while (WiFi.status() != WL_CONNECTED)
    {
        delay(500);
        Serial.print(".");
    }
    Serial.println("\nWi-Fi Connected.");
}

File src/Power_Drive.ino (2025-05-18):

#include <Wire.h>
#include <Adafruit_PWMServoDriver.h>
#include <WiFi.h>
#include <PubSubClient.h>
#include <AccelStepper.h>

// PWM Servo Driver
Adafruit_PWMServoDriver pwm = Adafruit_PWMServoDriver(0x40);

// Servo Channels
// #define BASE_SERVO 0
#define SHOULDER_SERVO 0
#define ELBOW_SERVO 1
#define WRIST_SERVO 2

// Stepper Motor (Base Rotation)
#define STEP_PIN 4
#define DIR_PIN 2
AccelStepper stepper(AccelStepper::DRIVER, STEP_PIN, DIR_PIN);

// Servo Angles
int baseAngle = 0, shoulderAngle = 0, elbowAngle = 0, wristAngle = 0;
bool gripperClosed = false;

// Wi-Fi and MQTT Credentials
const char *ssid = "Your_SSID";
const char *password = "Your_PASSWORD";
const char *mqttServer = "broker.emqx.io";
const int mqttPort = 1883;
const char *mqttUser = "Your_MQTT_Username";
const char *mqttPassword = "Your_MQTT_Password";

// Led Pins
const int wifiLedPin = 19;  // Wi-Fi LED on GPIO-19
const int mqttLedPin = 18;  // MQTT LED on GPIO-18

float prevAngles[2] = {0, 0};  // 2 joints 
const float MAX_STEP = 3.0;             // Maximum angle change per update (degrees)

// MQTT Client
WiFiClient espClient;
PubSubClient mqttClient(espClient);

// Function Prototypes
void updateServos();
void mqttCallback(char *topic, byte *message, unsigned int length);
int angleToPulse(int angle);
void controlStepper(float angle);
void smoothStartToAngle(int channel, int targetAngle, int delayMs = 20);

/**
 * @brief Initializes the serial communication, I2C bus, PWM servo driver, and stepper motor.
 *        Connects to WiFi and MQTT broker.
 * @details
 * - Initializes serial communication with a baud rate of 115200.
 * - Initializes the I2C bus.
 * - Initializes the PWM servo driver and sets the PWM frequency to 50 Hz.
 * - Initializes the stepper motor and sets its maximum speed and acceleration.
 * - Connects to WiFi with the provided ssid and password.
 * - Connects to the MQTT broker at the provided server and port.
 * - Subscribes to the "robot/angles" topic.
 * - Updates the servo angles to the initial values.
 */
void setup()
{
    Serial.begin(115200);
    Wire.begin();

    pinMode(wifiLedPin, OUTPUT);  // Set Wi-Fi LED pin as output
    pinMode(mqttLedPin, OUTPUT);  // Set MQTT LED pin as output
    
    pwm.begin();
    pwm.setPWMFreq(50);

    stepper.setMaxSpeed(3000);
    stepper.setAcceleration(3000);

    smoothStartToAngle(SHOULDER_SERVO,0);
    smoothStartToAngle(ELBOW_SERVO,0);

    WiFi.begin(ssid, password);
    mqttClient.setServer(mqttServer, mqttPort);
    mqttClient.setCallback(mqttCallback);

    while (WiFi.status() != WL_CONNECTED)
    {
        Serial.print(".");
        delay(500);
    }
    Serial.println("WiFi connected!");
    updateLedStatus();  // Update LED status after Wi-Fi is connected

    while (!mqttClient.connected())
    {
        Serial.print("Connecting to MQTT...");
        if (mqttClient.connect("ESP32_ACTUATOR", mqttUser, mqttPassword))
        {
            Serial.println("Connected to MQTT.");
            mqttClient.subscribe("robot/angles");
            updateLedStatus();  // Update LED status after MQTT is connected
        }
        else
        {
            Serial.println("Failed. Retrying...");
            delay(2000);
        }
    }
    updateServos();
    updateLedStatus();  // Update LED status
}

/**
 * @brief Main loop of the program.
 *        Checks for any MQTT messages and updates the stepper motor
 *        if a new angle is received.
 */
void loop()
{
    mqttClient.loop();
    stepper.run();
}

/**
 * @brief MQTT callback function.
 *        Updates the servo angles and the stepper motor when an MQTT message is received.
 *        The message should be in the format "SX:<angleServoX>,SY2:<angleServoY2>,ST:<angleStepperY>,GR:<grip>".
 * @param[in] topic MQTT topic of the message.
 * @param[in] message MQTT message payload.
 * @param[in] length Length of the MQTT message payload.
 */
void mqttCallback(char* topic, byte* message, unsigned int length) {
    String data;
    for (unsigned int i = 0; i < length; i++) {
        data += (char)message[i];
    }
    // Print received data for debugging purposes uncomment if needed
    // Serial.println("Received: " + data); 
    
    float angleServoX, angleServoY2, angleStepperY;
    int grip;
    sscanf(data.c_str(), "SX:%f,SY2:%f,ST:%f,GR:%d", &angleServoX, &angleServoY2, &angleStepperY, &grip);

    shoulderAngle = map(angleServoX, -90, 90, 0, 180);
    elbowAngle = map(angleServoY2, -90, 90, 0, 180);
    gripperClosed = grip;

    controlStepper(angleStepperY);
    updateServos();
}

/**
 * @brief Move the stepper motor to a specific angle.
 *        The angle should be between -90 and 90 degrees.
 *        The stepper motor will move to the specified angle and stop.
 * @param[in] angle Angle to move the stepper motor to, in degrees.
 */
void controlStepper(float angle)
{
    stepper.moveTo(map(angle, -90, 90, -3200, 3200));
}


/**
 * @brief Updates the servo motor positions for shoulder, elbow, and wrist joints.
 *        The function ensures smooth transitions by limiting the change in angle
 *        per update to a maximum step size. The wrist servo is controlled based
 *        on the gripper state, either fully open or fully closed.
 * @details
 * - The shoulder and elbow servo angles are updated incrementally to ensure smooth movement.
 * - The delta angle is capped by MAX_STEP to prevent abrupt movements.
 * - The wrist servo is set to 0 degrees if the gripper is closed and 180 degrees if open.
 */
void updateServos()
{
    // Shoulder
    float deltaS = shoulderAngle - prevAngles[0];
    if (abs(deltaS) > MAX_STEP) deltaS = (deltaS > 0) ? MAX_STEP : -MAX_STEP;
    prevAngles[0] += deltaS;
    // Serial.println("Old S: " + String(shoulderAngle) + " New S: " + String(prevAngles[0])); // For debugging uncomment if needed
    pwm.setPWM(SHOULDER_SERVO, 0, angleToPulse(prevAngles[0]));

    // Elbow
    float deltaE = elbowAngle - prevAngles[1];
    if (abs(deltaE) > MAX_STEP) deltaE = (deltaE > 0) ? MAX_STEP : -MAX_STEP;
    prevAngles[1] += deltaE;
    // Serial.println("Old E: " + String(elbowAngle) + " New E: " + String(prevAngles[1])); // For debugging uncomment if needed
    pwm.setPWM(ELBOW_SERVO, 0, angleToPulse(prevAngles[1]));

    pwm.setPWM(WRIST_SERVO, 0, angleToPulse(gripperClosed ? 0 : 180));
}

/**
 * @brief Converts an angle in degrees to a pulse length suitable for controlling a servo motor.
 *        The angle should be in the range of 0-180 degrees.
 *        The pulse length is mapped from the range of 0-180 degrees to the range of 150-600,
 *        which is a good range for most servo motors.
 * @param[in] angle Angle to convert, in degrees.
 * @return Pulse length suitable for controlling a servo motor, in microseconds.
 */
int angleToPulse(int angle)
{
    int pulse = map(angle, 0, 180, 150, 600); // 150-600 is a good range for most servos
    return pulse;
}
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
